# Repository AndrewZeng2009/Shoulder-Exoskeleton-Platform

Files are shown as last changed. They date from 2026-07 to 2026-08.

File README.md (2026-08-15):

# Shoulder Exoskeleton Platform
An open-source, low-cost (~$300) cable-driven shoulder exoskeleton designed as an accessible research and prototyping platform. Most existing shoulder exoskeleton platforms are expensive, proprietary, and inaccessible to small research groups, students, and independent developers. This platform addresses that gap by integrating established actuation and sensing technologies into a reproducible, modifiable system that can be fabricated with off-the-shelf components and a standard 3D printer.

The system combines a servo-driven Bowden cable transmission with passive bungee elastic assistance and a tri-modal sensor suite — surface EMG, IMU, and load cell — controlled through an Arduino Uno. An IR remote switches between off, sensor-only, and active assistance modes, with an adjustable EMG activation threshold. Experimental validation demonstrated 27–42% reduction in deltoid muscle activation under active assistance across a range of loads and motions.

The target audience is the open-source community: students, hobbyists, and small labs who want to experiment with exoskeleton hardware, sensing modalities, and control algorithms without a large resource investment.

---

## Repository Structure

**CAD/**
- `native/` — Fusion 360 source files (.f3z)
- `step/` — Universal CAD files (.step)
- `stl/` — 3D-printable components (.stl)

**Electronics/**
- `Simple Schematic.png` — Full wiring diagram

**Firmware/**
- `Shoulder_Exoskeleton_System_Code.ino` — Arduino control firmware
- `State Machine Diagram.png` — Control state machine diagram

**Summary Data/**
- `EMG Data.pdf` — Processed EMG results across all assistance conditions, loads, and motions
- `IMU Data.pdf` — Processed range-of-motion (Euler angle) data
- `Torque Data.pdf` — Processed bench and in-vivo torque results

**Docs/**
- `BOM.md` — Bill of materials with sourcing and pricing
- `Assembly_Guide.pdf` — Step-by-step build instructions

---

## Getting Started
1. Print all STL components and source hardware per `Docs/BOM.md`
2. Assemble the platform following `Docs/Assembly_Guide.pdf`
3. Wire electronics per `Electronics/Simple Schematic.png`
4. Upload `Firmware/Shoulder_Exoskeleton_System_Code.ino` to an Arduino Uno
5. Open Serial Monitor at 115200 baud to verify all sensors

---

## Contact
Andrew Zeng — andrew10n06@gmail.com

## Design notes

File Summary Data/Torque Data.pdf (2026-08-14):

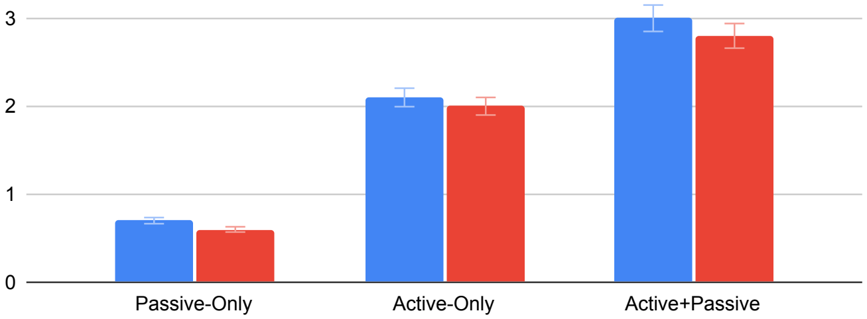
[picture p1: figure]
Passive-Only; Active-Only; Active+Passive

Assistance Condition

Torque (Nm)

4

Bench Torque | In-Vivo Torque

## Peak Torque Comparison

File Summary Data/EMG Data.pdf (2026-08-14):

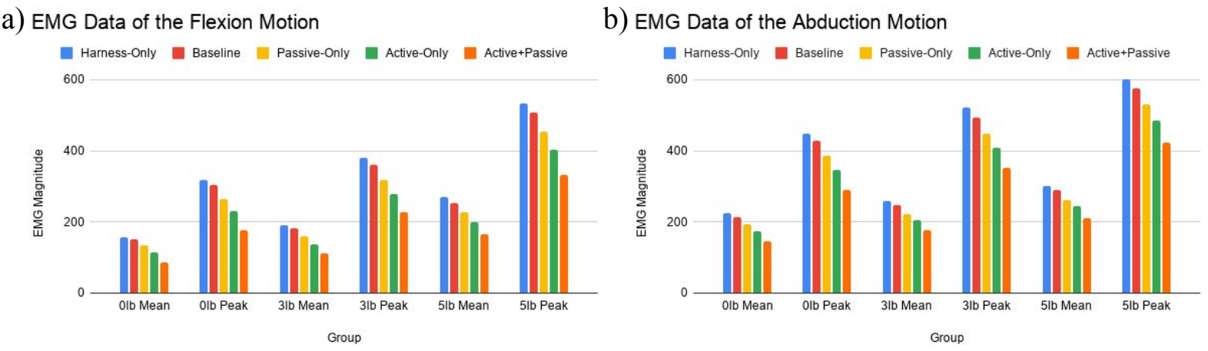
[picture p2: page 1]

a) b)

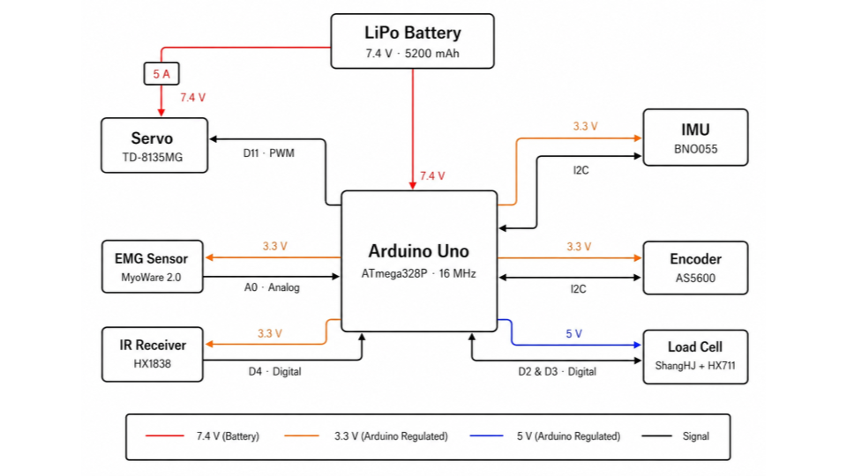
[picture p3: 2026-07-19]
Electronics/Simple Schematic.png

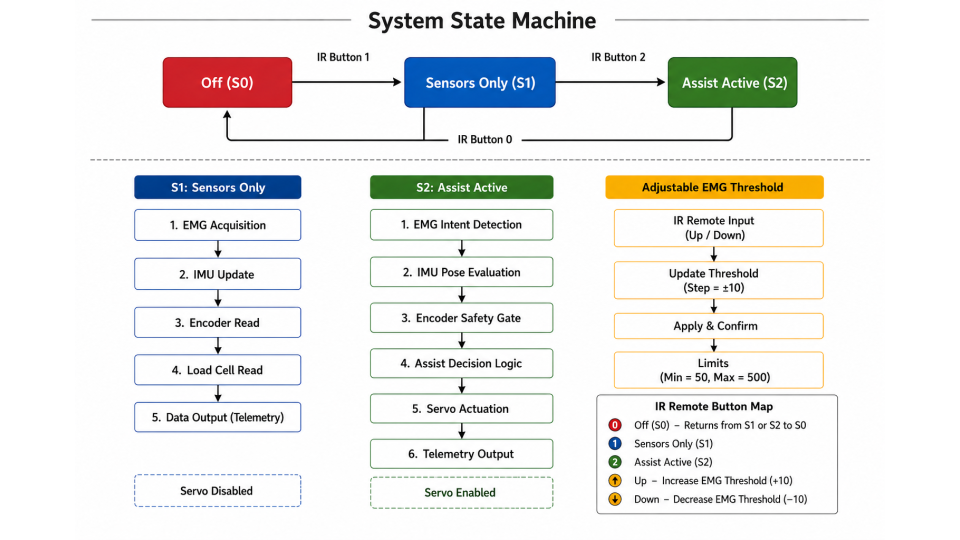
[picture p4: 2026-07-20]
Firmware/State Machine Diagram.png

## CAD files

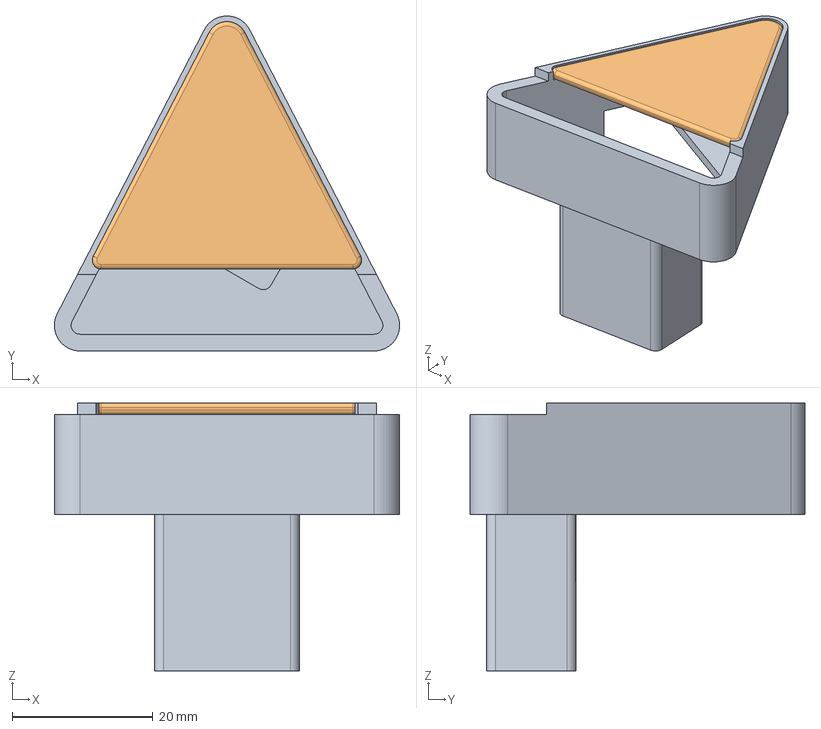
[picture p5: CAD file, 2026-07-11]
CAD/step/EMGmount.step
49.1 x 47.7 x 38.1 mm

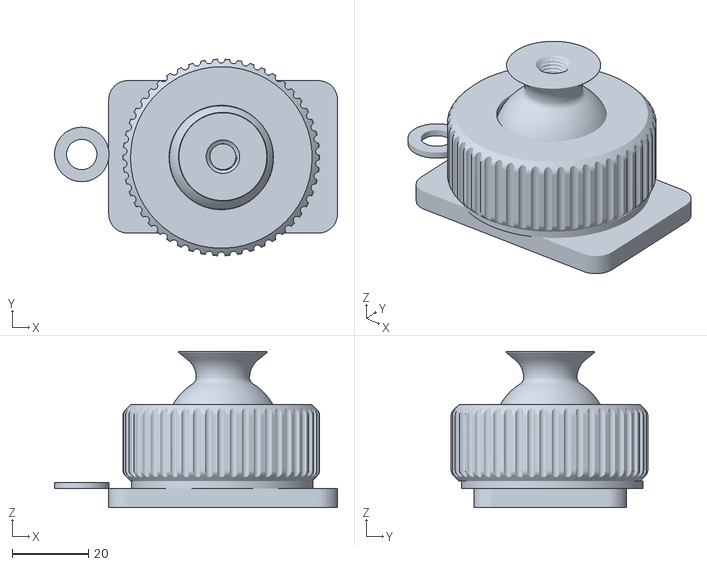
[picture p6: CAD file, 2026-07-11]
CAD/stl/Ball Joint.stl
74.2 x 51.6 x 41.0

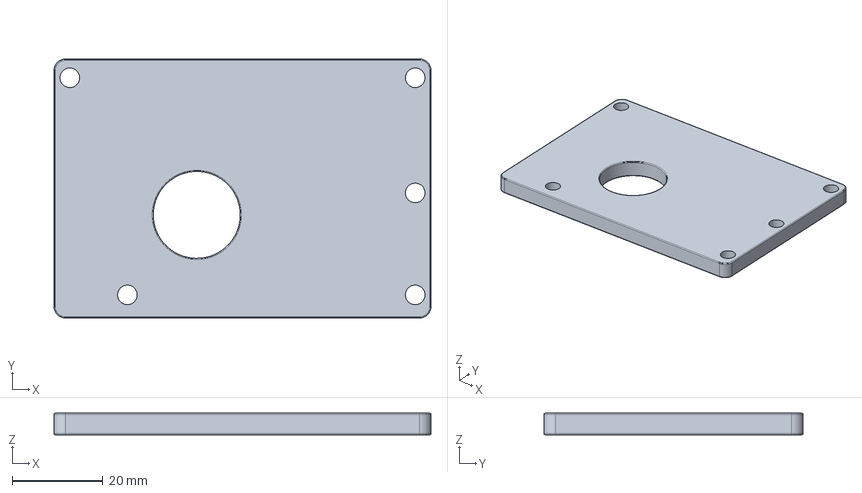
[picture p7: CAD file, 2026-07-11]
CAD/step/ServoPlate.step
83.2 x 57.1 x 4.76 mm

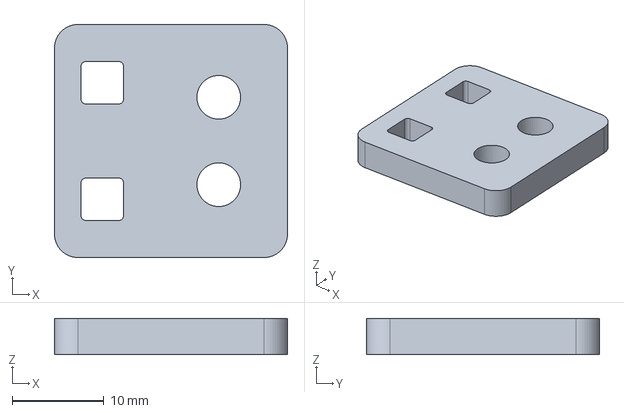
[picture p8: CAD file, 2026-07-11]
CAD/step/Load Cell Mount.step
25.4 x 25.4 x 3.97 mm

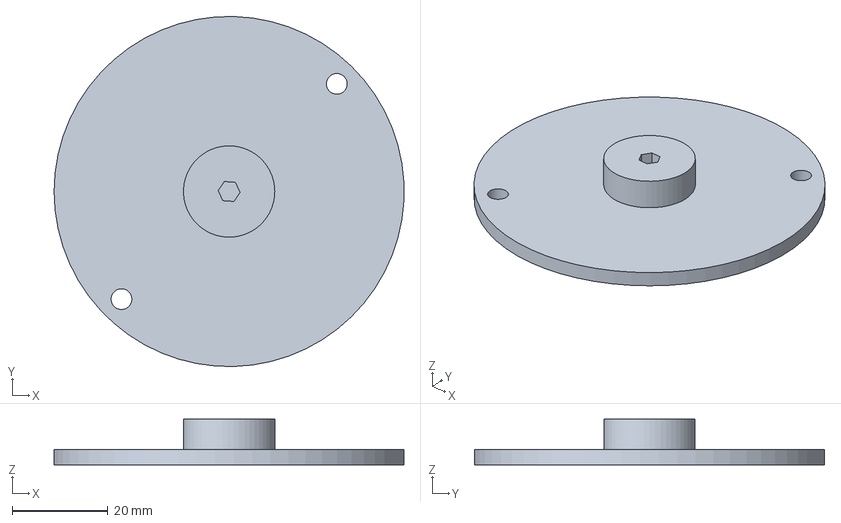
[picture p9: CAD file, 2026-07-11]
CAD/step/Winch2.step
73.0 x 73.0 x 9.52 mm

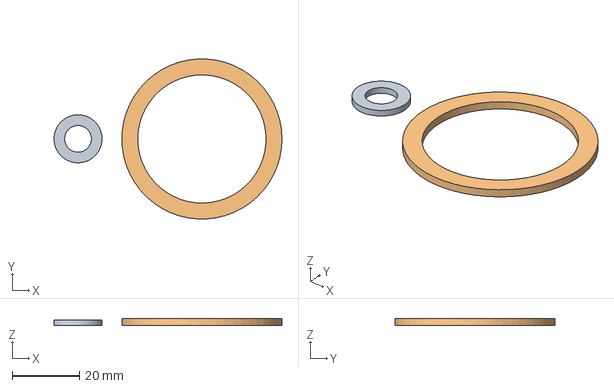
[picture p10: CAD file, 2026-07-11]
CAD/step/Spacers.step
67.8 x 47.5 x 2.00 mm

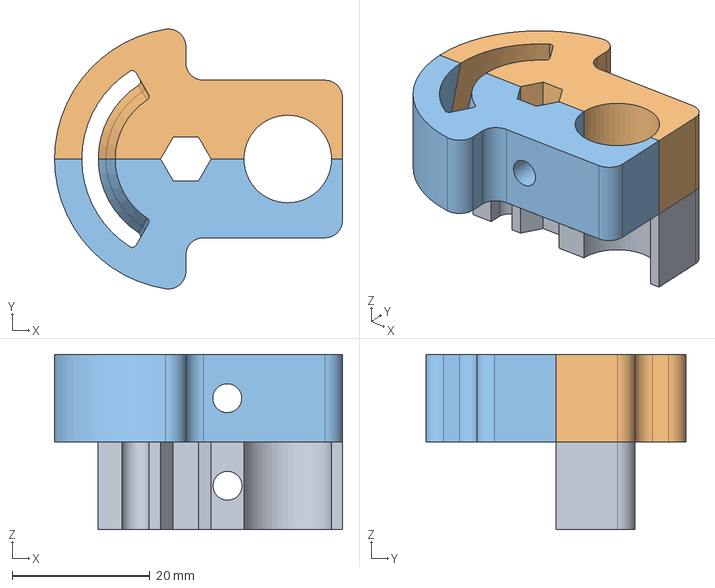
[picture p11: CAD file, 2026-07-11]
CAD/step/CableHolder.step
41.8 x 37.7 x 25.4 mm

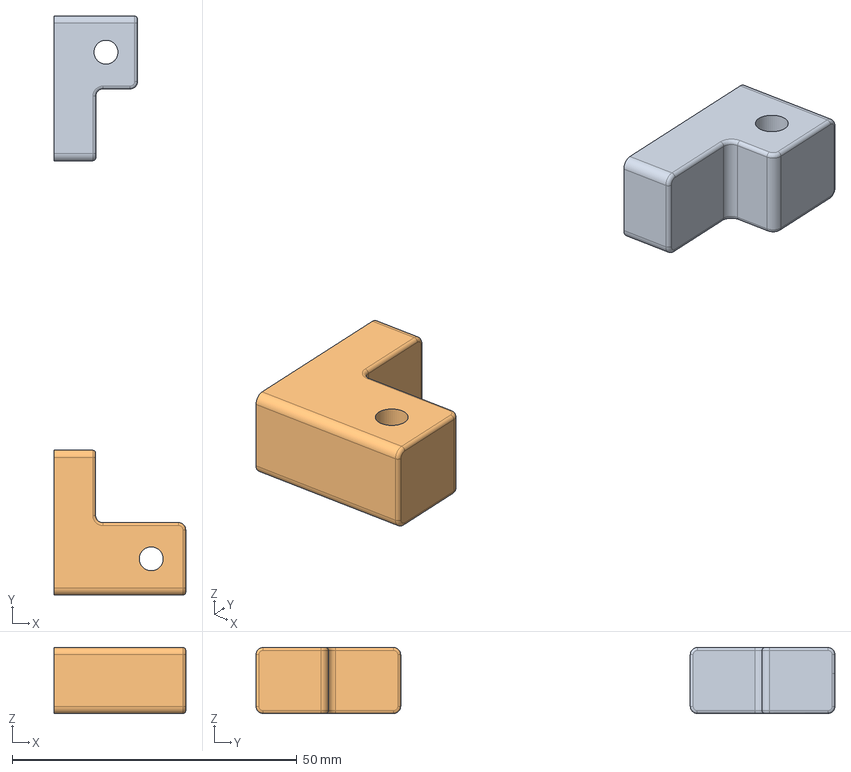
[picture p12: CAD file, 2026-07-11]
CAD/step/CableMount.step
23.1 x 101.6 x 11.6 mm

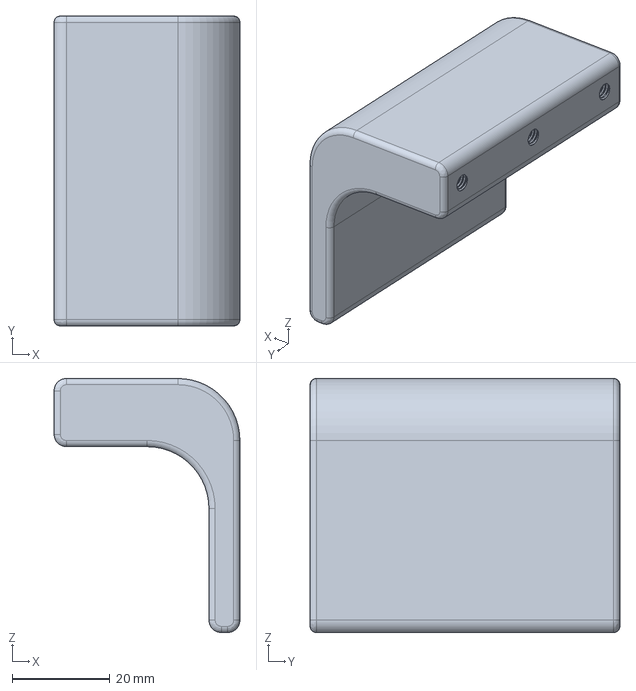
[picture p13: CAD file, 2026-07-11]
CAD/step/Arm Strap Support1.step
38.1 x 63.5 x 52.1 mm

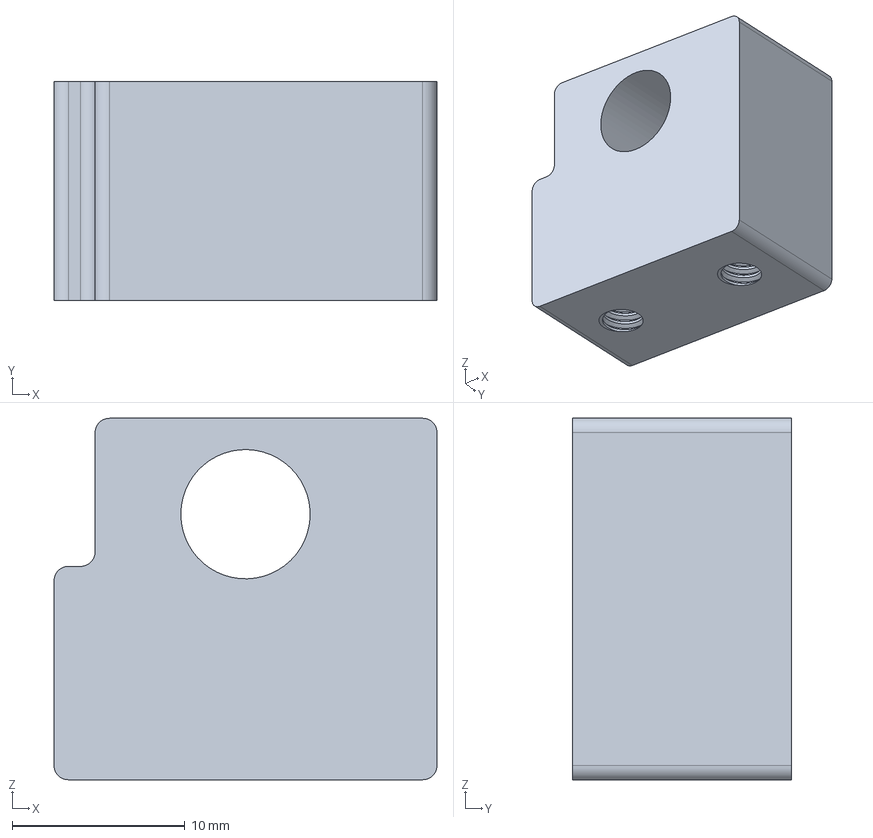
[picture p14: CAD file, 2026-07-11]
CAD/step/StandoffHolder.step
22.2 x 12.7 x 21.0 mm

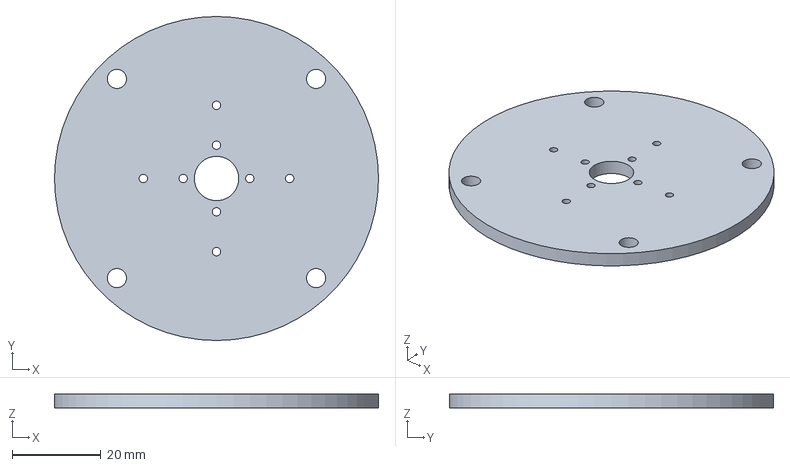
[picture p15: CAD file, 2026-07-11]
CAD/step/Winch1.step
73.0 x 73.0 x 3.17 mm

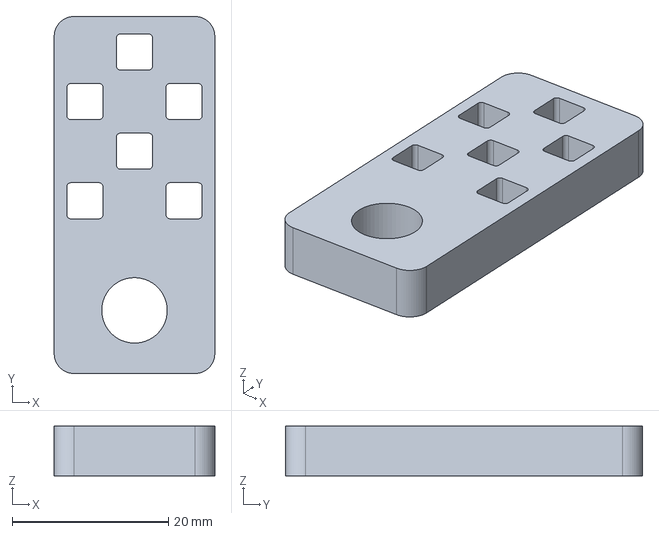
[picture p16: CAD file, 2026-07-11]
CAD/step/C-ChannelExtension.step
20.6 x 45.7 x 6.35 mm

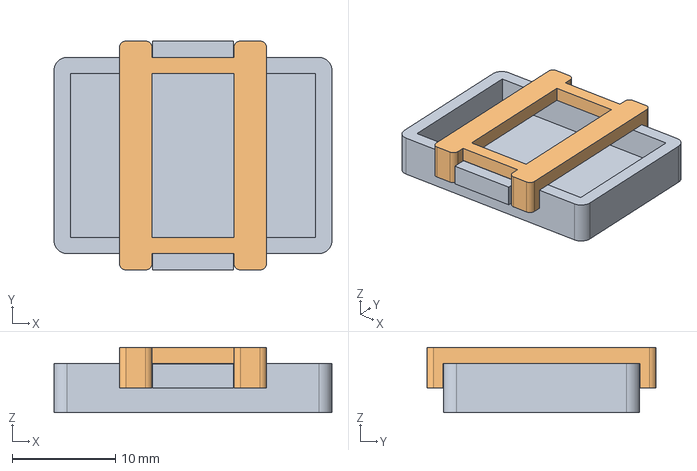
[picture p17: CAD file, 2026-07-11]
CAD/step/IRreceiverMount.step
27.0 x 22.2 x 6.35 mm

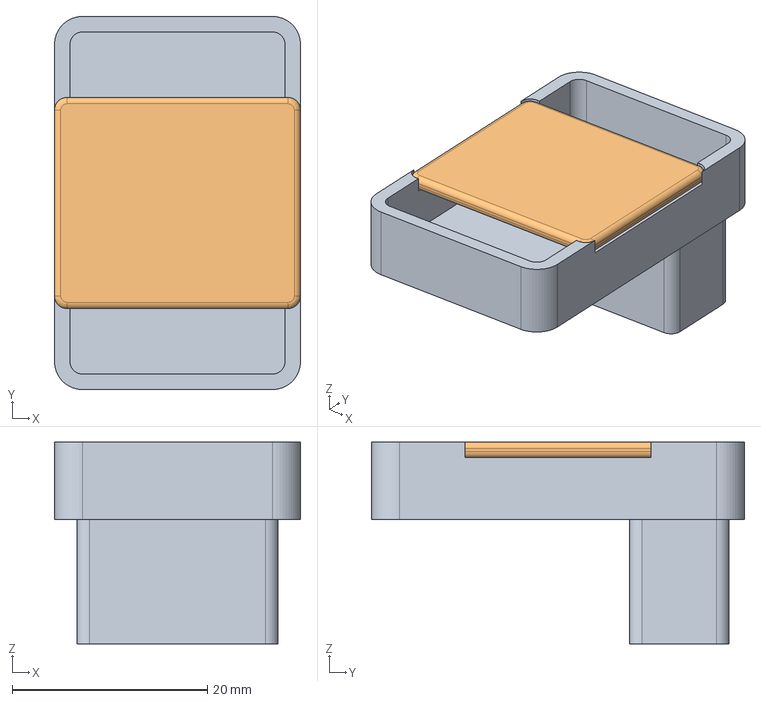
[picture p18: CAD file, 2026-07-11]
CAD/step/HX711mount.step
25.2 x 38.2 x 20.6 mm

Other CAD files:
CAD/step/ElasticMount.step
CAD/step/Encoder Mount.step
CAD/step/IMUmount.step
CAD/step/ServoMount.step
CAD/native/Arm Strap Support1.f3d
CAD/native/Arm Strap Support2.f3d
CAD/native/C-ChannelExtension.f3d
CAD/native/CableHolder.f3d
CAD/native/CableMount.f3d
CAD/native/EMGmount.f3d
CAD/native/ElasticMount.f3d
CAD/native/Encoder Mount.f3d
CAD/native/HX711mount.f3d
CAD/native/IMUmount.f3d
CAD/native/IRreceiverMount.f3d
CAD/native/Load Cell Mount.f3d
CAD/native/ServoBox.f3z
CAD/native/ServoMount.f3d
CAD/native/ServoPlate.f3d
CAD/native/Spacers.f3d
CAD/native/StandoffHolder.f3d
CAD/native/Winch1.f3d
CAD/native/Winch2.f3d
CAD/step/Arm Strap Support2.step
CAD/step/ServoBox.step
CAD/stl/Arm Strap Support1.stl
CAD/stl/Arm Strap Support2.stl
CAD/stl/C-ChannelExtension.stl
CAD/stl/CableHolder.stl
CAD/stl/CableMount.stl
CAD/stl/EMGmount.stl
CAD/stl/ElasticMount.stl
CAD/stl/Encoder Mount.stl
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

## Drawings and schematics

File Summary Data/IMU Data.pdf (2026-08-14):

## Euler Angles of Varying Motions

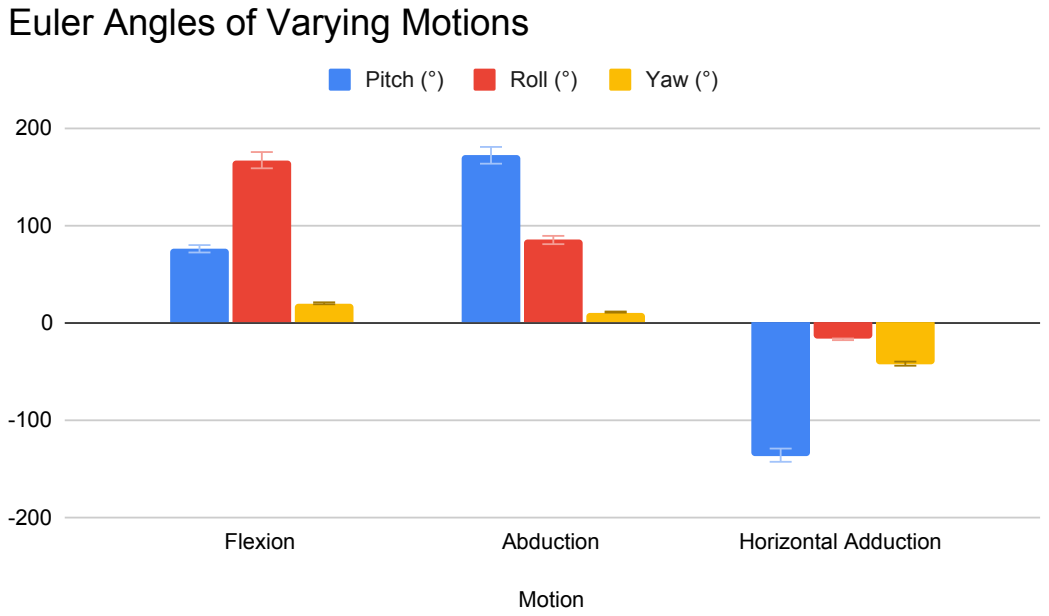
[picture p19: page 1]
Motion; Flexion; Abduction; Horizontal Adduction; Pitch (°); Roll (°); Yaw (°)

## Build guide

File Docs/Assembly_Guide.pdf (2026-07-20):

# Assembly Guide

Cable-Driven Shoulder Exoskeleton Research Platform

A high-level build guide. For precise geometry and dimensions refer to the CAD files in CAD/. For wiring refer to Electronics/Simple Schematic.png.

### 1. 3D Printing

All printable components are in CAD/stl/. Print all parts before beginning assembly.

Component | Qty | Description

Arm Strap Support 1 &

2 | 1 ea. | Supports the arm bar and serves as attachment point for Velcro straps
Ball Joint | 1 | Mounts the entire exoskeleton frame to the hip/belt
C-Channel Extension | 1 | Connects the C-channel frame to the ball joint
Cable Holder | 3 | Guides the Bowden cable and bungee cord along the length of the frame
Cable Mount | 1 | Attaches the Bowden cable to the arm bar on either side of the fulcrum
EMG Mount | 1 | Mount for the MyoWare 2.0 EMG sensor
Elastic Mount | 1 | Mount for the bungee cord passive elastic element
Encoder Mount | 1 | Mount for the AS5600 encoder sensor
HX711 Mount | 1 | Mount for the HX711 load cell amplifier board
IMU Mount | 1 | Mount for the BNO055 IMU sensor
IR Receiver Mount | 1 | Mount for the HX1838 IR receiver
Load Cell Mount | 4 | Connects both halves of the arm bar through the load cell
Servo Mount | 1 | Mount for the servo motor
Servo Plate | 1 | Closes the servo gearbox housing
Spacers | Var. | Miscellaneous spacers used throughout the assembly
Standoff Holder | 2 | Secures the aluminum standoff frame to the C-channel
Winch 1 & 2 | 1 ea. | Attach to the servo head and drive the Bowden cable; encoder magnet is embedded in the winch

Print settings: 0.2 mm layer height, 20% infill for most parts, 50% infill for load-bearing components (Servo Mount, Load Cell Mount, Arm Strap Supports, Ball Joint).

### 2. Frame Assembly

1. Attach the Standoff Holders to the aluminum C-channel to form the vertical spine of the frame.
2. Insert aluminum standoffs into the Standoff Holders to connect the spine to the shoulder region.
3. Attach the C-Channel Extension to the bottom of the spine.
4. Mount the Ball Joint onto the C-Channel Extension — this is the primary attachment point to the user's hip/belt.

### 3. Servo Assembly

1. Seat the servo motor into the Servo Mount and close with the Servo Plate.
2. Attach Winch 1 then Winch 2 to the servo output shaft. The magnet embedded in the winch faces the AS5600 encoder.

### 3. Mount the Encoder Mount so the AS5600 sensor faces the magnet. Set ENCODER_OFFSET in

firmware to zero at the neutral arm position.

4. Mount the full servo assembly onto the C-channel frame at shoulder blade height.

### 4. Bowden Cable and Passive Elastic Routing

1. Thread the inner bicycle cable through the Bowden cable housing.
2. Anchor the sheath at the servo end and route it along the frame, securing at intervals with the Cable Holders.
3. Attach the far end of the inner cable to the arm bar via the Cable Mount on either side of the load cell fulcrum.
4. Attach the bungee cord at both ends using the Elastic Mounts — one on the frame near the shoulder and one on the arm bar. Adjust the anchor position to set passive preload and mark it for consistent re-tensioning between sessions.

### 5. Arm Bar Assembly

The arm bar runs along the upper arm from the shoulder pivot to just above the elbow. Refer to CAD/step/ for the full sub-assembly.

1. Assemble the arm bar halves through the four Load Cell Mounts with the load cell seated inline so cable force passes through it.

2. Mount the HX711 board on the arm bar using the HX711 Mount.
3. Attach the two Arm Strap Supports along the arm bar and thread Velcro straps through them to secure the bar to the arm.
4. Mount the IMU Mount near the proximal end of the arm bar and seat the BNO055.
5. Mount the EMG Mount near the deltoid and connect the MyoWare 2.0 sensor.

### 6. Harness Integration

1. Thread the C-channel spine through the back of the tactical harness and secure with Velcro strips along the spine.
2. Attach the waist strap to the bottom of the assembly.
3. Connect the arm bar to the top of the spine via the shoulder pivot.
4. Mount the IR Receiver Mount on the frame with clear line-of-sight for the remote.
5. Route and bundle all sensor wires along the spine using cable cover sleeving.

### 7. Electronics

Refer to Electronics/Simple Schematic.png for all connections.

1. Mount the Arduino Uno on the electronics panel at the waist.
2. Connect the LiPo battery to the Arduino and servo via the 5A inline fuse.
3. Wire all sensors to the Arduino per the schematic.
4. Add the capacitor across the servo power rails.

### 8. Firmware

1. Install the Arduino IDE and the following libraries via Library Manager: Adafruit BNO055, Adafruit Unified Sensor, Adafruit AS5600, HX711 by bogde, IRremote.
2. Open Firmware/Shoulder_Exoskeleton_System_Code.ino and upload to the Arduino Uno.
3. Open Serial Monitor at 115200 baud to verify all sensors are detected.

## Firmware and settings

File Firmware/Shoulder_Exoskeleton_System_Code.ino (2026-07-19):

#include <Wire.h>
#include <Adafruit_Sensor.h>
#include <Adafruit_BNO055.h>
#include <Adafruit_AS5600.h>
#include <Servo.h>
#include "HX711.h"
#include <IRremote.h>

const int IR_RECEIVER_PIN = 4;
#define IR_BUTTON_0 0xE916FF00
#define IR_BUTTON_1 0xF30CFF00
#define IR_BUTTON_2 0xE718FF00
#define IR_BUTTON_UP 0xF609FF00
#define IR_BUTTON_DOWN 0xF807FF00

int systemMode = 0;

const int EMG_PIN = A0;
const int EMG_SMOOTH_SAMPLES = 10;
const int EMG_THRESHOLD_MIN = 50;
const int EMG_THRESHOLD_MAX = 500;
const int EMG_THRESHOLD_STEP = 10;
int EMG_THRESHOLD = 150;

float emgReadings[EMG_SMOOTH_SAMPLES];
int emgIndex = 0;
long emgTotal = 0;
int emgAverage = 0;

Servo myServo;
const int SERVO_PIN = 11;
int servoCommand = 1500;
bool servoAttached = false;

Adafruit_BNO055 bno = Adafruit_BNO055(55);
sensors_event_t imuEvent;

Adafruit_AS5600 as5600;
const int ENCODER_OFFSET = 1750;

#define HX711_DOUT 3
#define HX711_CLK 2
HX711 scale;

const int LOAD_SMOOTH_SAMPLES = 10;
const float GRAMS_PER_COUNT = 0.01134;
float loadReadings[LOAD_SMOOTH_SAMPLES];
int loadIndex = 0;
float loadTotal = 0;
float loadAverage = 0;

float getSmoothedEMG() {
  int rawEMG = analogRead(EMG_PIN);
  emgTotal -= emgReadings[emgIndex];
  emgReadings[emgIndex] = rawEMG;
  emgTotal += emgReadings[emgIndex];
  emgIndex = (emgIndex + 1) % EMG_SMOOTH_SAMPLES;
  emgAverage = emgTotal / EMG_SMOOTH_SAMPLES;
  return emgAverage;
}

uint16_t getScaledAngle() {
  uint16_t rawAngle = as5600.getRawAngle();
  return (rawAngle + 4096 - ENCODER_OFFSET) % 4096;
}

bool isMagnetOK() {
  return as5600.isMagnetDetected();
}

void updateServo(float emgValue, bool magnetOK, uint16_t encoderAngle) {
  int newCommand = 1500;
  if (magnetOK && encoderAngle > 2000)
    newCommand = 1500;
  else if (emgValue > EMG_THRESHOLD && encoderAngle > 1000)
    newCommand = 1750;

  if (!servoAttached) {
    myServo.attach(SERVO_PIN);
    servoAttached = true;
  }
  myServo.writeMicroseconds(newCommand);
  servoCommand = newCommand;
}

void detachServoIfAttached() {
  if (servoAttached) {
    myServo.detach();
    servoAttached = false;
  }
}

float getSmoothedLoadCellGrams() {
  if (!scale.is_ready()) return loadAverage;
  float grams = scale.read() * GRAMS_PER_COUNT;
  loadTotal -= loadReadings[loadIndex];
  loadReadings[loadIndex] = grams;
  loadTotal += loadReadings[loadIndex];
  loadIndex = (loadIndex + 1) % LOAD_SMOOTH_SAMPLES;
  loadAverage = loadTotal / LOAD_SMOOTH_SAMPLES;
  return loadAverage;
}

void setup() {
  Serial.begin(115200);
  delay(500);

  IrReceiver.begin(IR_RECEIVER_PIN, ENABLE_LED_FEEDBACK);

  myServo.attach(SERVO_PIN);
  servoAttached = true;
  myServo.writeMicroseconds(1500);

  for (int i = 0; i < EMG_SMOOTH_SAMPLES; i++) emgReadings[i] = 0;
  for (int i = 0; i < LOAD_SMOOTH_SAMPLES; i++) loadReadings[i] = 0;

  if (!bno.begin()) {
    Serial.println("BNO055 not detected.");
    while (1)
      ;
  }
  delay(1000);
  bno.setExtCrystalUse(true);

  if (!as5600.begin()) {
    Serial.println("AS5600 not detected.");
    while (1)
      ;
  }
  as5600.enableWatchdog(false);
  as5600.setPowerMode(AS5600_POWER_MODE_NOM);
  as5600.setHysteresis(AS5600_HYSTERESIS_OFF);
  as5600.setOutputStage(AS5600_OUTPUT_STAGE_ANALOG_FULL);
  as5600.setSlowFilter(AS5600_SLOW_FILTER_16X);
  as5600.setFastFilterThresh(AS5600_FAST_FILTER_THRESH_SLOW_ONLY);
  as5600.setZPosition(0);
  as5600.setMPosition(4095);
  as5600.setMaxAngle(4095);

  scale.begin(HX711_DOUT, HX711_CLK);
  if (!scale.is_ready()) {
    Serial.println("HX711 not responding.");
  } else {
    scale.set_scale();
    scale.tare();
  }

  Serial.println("System initialized.");
  Serial.print("Mode: ");
  Serial.println(systemMode);
  Serial.print("EMG Threshold: ");
  Serial.println(EMG_THRESHOLD);
}

void loop() {
  if (IrReceiver.decode()) {
    uint32_t code = IrReceiver.decodedIRData.decodedRawData & 0xFFFFFFFF;

    if (code == IR_BUTTON_0) {
      systemMode = 0;
      Serial.println("Mode: 0 (OFF)");
    } else if (code == IR_BUTTON_1) {
      systemMode = 1;
      Serial.println("Mode: 1 (Sensors Only)");
    } else if (code == IR_BUTTON_2) {
      systemMode = 2;
      Serial.println("Mode: 2 (Sensors + Servo)");
    } else if (code == IR_BUTTON_UP) {
      EMG_THRESHOLD = min(EMG_THRESHOLD + EMG_THRESHOLD_STEP, EMG_THRESHOLD_MAX);
      Serial.print("EMG Threshold: ");
      Serial.println(EMG_THRESHOLD);
    } else if (code == IR_BUTTON_DOWN) {
      EMG_THRESHOLD = max(EMG_THRESHOLD - EMG_THRESHOLD_STEP, EMG_THRESHOLD_MIN);
      Serial.print("EMG Threshold: ");
      Serial.println(EMG_THRESHOLD);
    }

    IrReceiver.resume();
  }

  if (systemMode == 0) {
    detachServoIfAttached();
    delay(10);
    return;
  }

  float emgValue = getSmoothedEMG();
  bool magnetOK = isMagnetOK();
  uint16_t encoderAngle = magnetOK ? getScaledAngle() : 0;
  float grams = getSmoothedLoadCellGrams();

  bno.getEvent(&imuEvent);

  String out = "";
  out += "Raw EMG: " + String(analogRead(EMG_PIN));
  out += " | Smoothed: " + String(emgValue, 2);
  out += " | Threshold: " + String(EMG_THRESHOLD);
  out += " | Encoder: " + String(magnetOK ? encoderAngle : -1);
  out += " | IMU: " + String(imuEvent.orientation.x, 2) + "," + String(imuEvent.orientation.y, 2) + "," + String(imuEvent.orientation.z, 2);
  out += " | Load: " + String(grams, 2) + "g " + String(grams / 1000.0, 3) + "kg " + String((grams / 1000.0) * 9.80665, 2) + "N";

  if (systemMode == 1) {
    detachServoIfAttached();
  } else if (systemMode == 2) {
    updateServo(emgValue, magnetOK, encoderAngle);
    out += " | Servo: " + String(servoCommand);
  }

  Serial.println(out);
  delay(10);
}

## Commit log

2026-07-11 Initial commit: firmware and CAD files
    [Arm Strap Support1.f3d, Arm Strap Support1.step, Arm Strap Support1.stl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]
2026-07-11 Create BOM
